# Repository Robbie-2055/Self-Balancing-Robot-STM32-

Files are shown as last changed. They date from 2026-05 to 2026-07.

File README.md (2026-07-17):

# STM32 Self-Balancing Robot





A two-wheeled self-balancing inverted pendulum robot built using an **STM32** microcontroller. The robot utilizes an **MPU6050** Inertial Measurement Unit (IMU) to sense its orientation, processes this data through a PID loop, and drives two **DC shaft motors** via an **L298N** motor driver to maintain perfect equilibrium.

This project is split into two distinct execution phases: prototyping with off-the-shelf modules and migrating to a custom-designed Printed Circuit Board (PCB).

---

## 📌 Project Roadmap

- [x] **Phase 1: Breadboard Prototype** 
  - Wire STM32, MPU6050, and L298N on a chassis.
  - Implement basic I2C communication and PWM motor control.
- [ ] **Phase 2: Firmware Optimization**
  - Tune the PID parameters ($K_p$, $K_i$, $K_d$).
- [ ] **Phase 3: Custom PCB Layout**
  - Design a compact, integrated schematic in KiCad

---

## 🛠️ Hardware Architecture

### Phase 1: Prototype Components
* **Microcontroller:** STM32 (e.g., STM32F103C8T6 "Blue Pill") — Handles high-speed sensor parsing, PID calculation, and PWM generation.
* **IMU Sensor:** MPU6050 — Configured via I2C to read accelerometer and gyroscope raw data.
* **Motor Driver:** L298N Dual H-Bridge — Regulates power and direction to the motors based on logic signals from the STM32.
* **Actuators:** 2x DC Gear Shaft Motors (equipped with quadrature encoders for speed feedback).
* **Power Supply:** 3S LiPo battery (11.1V) to power the motors, stepped down via buck converter to 5V/3.3V for logic.

### Phase 2: Custom Board Upgrades
To reduce wiring complexity, eliminate inductive noise, and minimize the physical footprint:
* **Integrated MCU:** STM32 chip placed directly on-board with dedicated decoupling capacitors and an external crystal oscillator.
* **On-board Sensors:** Hardwired MPU6050 footprint to prevent I2C signal degradation over jumper wires.
* **Motor Driver:** The L298N Motor driver together with all support components placed directly on the custom board

---

## Current developments

https://github.com/user-attachments/assets/f44257d5-607a-4bce-967d-3fb6638ffd92



https://github.com/user-attachments/assets/f6ba3c8e-9986-4cd3-9cd2-4a73ed5fd0c9

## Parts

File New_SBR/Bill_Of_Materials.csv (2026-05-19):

Id | Designator | Footprint | Quantity | Designation | Supplier and ref
1 | R2,R1 | R_0402_1005Metric | 2 | 4.7K
2 | R9 | R_0402_1005Metric | 1 | 1k
3 | R8,R6 | R_0402_1005Metric | 2 | 4.7k
4 | D1 | LED_0402_1005Metric | 1 | LED
5 | C21 | C_0402_1005Metric | 1 | 2.2nF
6 | C20,C19,C3 | C_0402_1005Metric | 3 | 0.1uF
7 | U3 | InvenSense_QFN-24_4x4mm_P0.5mm_NoMask | 1 | MPU-6050
8 | U1 | LQFP-64_10x10mm_P0.5mm | 1 | STM32F411RCTx
9 | D4,D5,D8,D10,D6,D7,D9,D11 | D_0603_1608Metric | 8 | 1N4007
10 | C15 | C_0603_1608Metric | 1 | 0.01uF
11 | C14,C16 | C_0603_1608Metric | 2 | 4.7uF
12 | C23,C25,C26,C1,C4,C2,C24 | C_0603_1608Metric | 7 | 100nF
13 | C12,C13 | C_0603_1608Metric | 2 | 1.5pF
14 | D12 | LED_0603_1608Metric | 1 | LED
15 | J1,J2 | TerminalBlock_Xinya_XY308-2.54-2P_1x02_P2.54mm_Horizontal | 2 | Screw_Terminal_01x02
16 | U4 | TO-220-15_P2.54x5.08mm_StaggerOdd_Lead4.58mm_Vertical | 1 | L298N
17 | R3,R4,R7 | R_0603_1608Metric | 3 | 10K
18 | J3 | TerminalBlock_Xinya_XY308-2.54-3P_1x03_P2.54mm_Horizontal | 1 | Screw_Terminal_01x03
19 | R5 | R_0603_1608Metric | 1 | 1K
20 | C27 | C_0603_1608Metric | 1 | 10uF
21 | J4 | PinSocket_1x06_P2.54mm_Vertical | 1 | Conn_01x06_Socket
22 | C9 | C_0603_1608Metric | 1 | 2.2uF
23 | C10,C11 | C_0603_1608Metric | 2 | 20pF
24 | C17,C18 | C_0603_1608Metric | 2 | 220uF
25 | PWR_SW3 | SW_Slide_SPDT_Straight_CK_OS102011MS2Q | 1 | SW_SPDT
26 | RESET1 | SW_SPST_TL3305A | 1 | SW_Push
27 | J6 | PinSocket_1x04_P2.54mm_Vertical | 1 | Conn_01x04_Socket
28 | 9v_PWR1 | PinHeader_1x02_P2.54mm_Vertical | 1 | Jumper_3
29 | 5v_Reg1 | TO-220-3_Vertical | 1 | LM7805_TO220
30 | 3.3V_Reg1 | TO-220-3_Vertical | 1 | LM1117T-3.3
31 | Y1 | Crystal_HC49-U_Vertical | 1 | 25MHZ 9PF
32 | Y2 | Crystal_C38-LF_D3.0mm_L8.0mm_Vertical | 1 | 32.768K 6PF

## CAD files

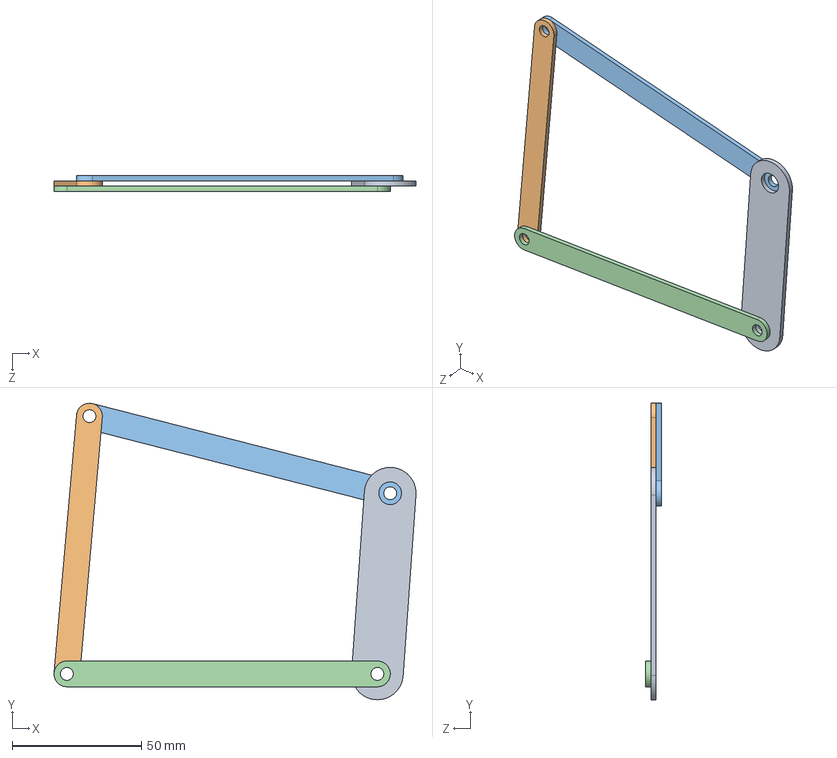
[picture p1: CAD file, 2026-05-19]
Project Selfbalancing robot/4bar_linkage.SLDASM
139.9 x 114.6 x 6.00 mm
link1
link2
link3
link4

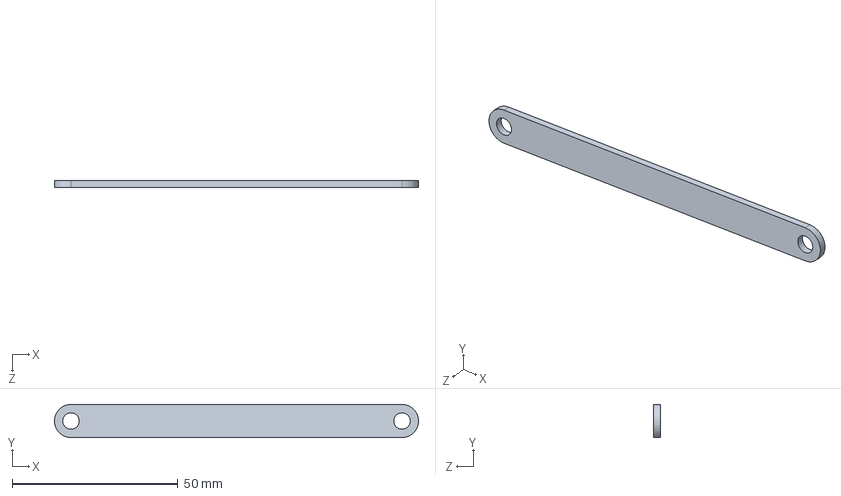
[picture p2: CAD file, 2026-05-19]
Project Selfbalancing robot/Links/link3.SLDPRT
110.0 x 10.0 x 2.00 mm

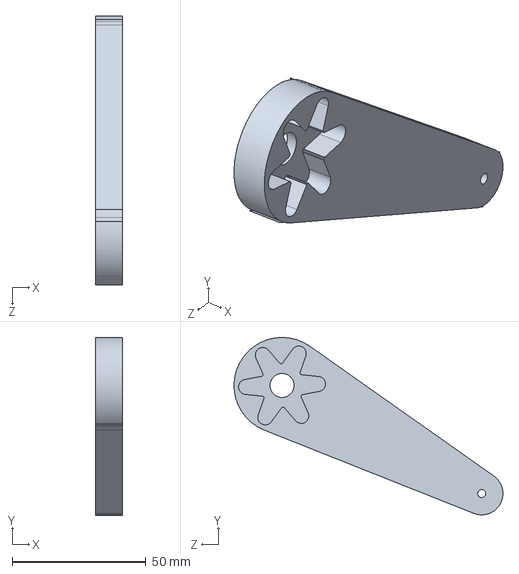
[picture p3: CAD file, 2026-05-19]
Project Selfbalancing robot/thigh-2_faces.SLDPRT
10.0 x 66.7 x 100.7 mm

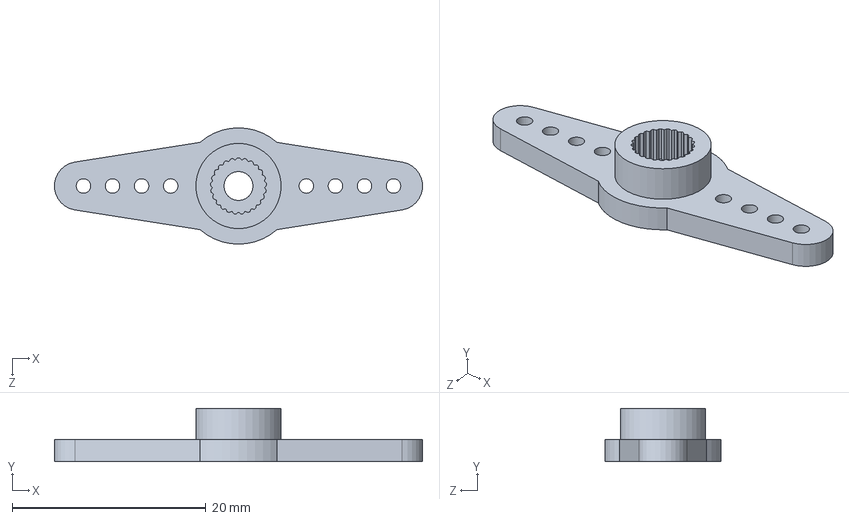
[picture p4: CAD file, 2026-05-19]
Project Selfbalancing robot/2horn_mount.SLDPRT
38.0 x 5.50 x 12.0 mm

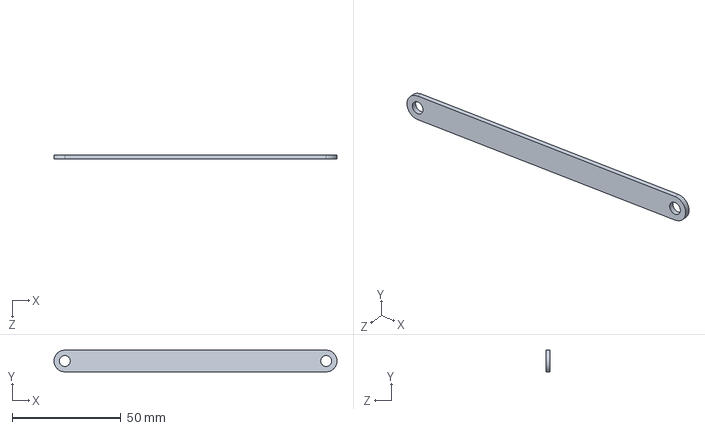
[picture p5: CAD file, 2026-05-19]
Project Selfbalancing robot/Links/link2.SLDPRT
130.0 x 10.0 x 2.00 mm

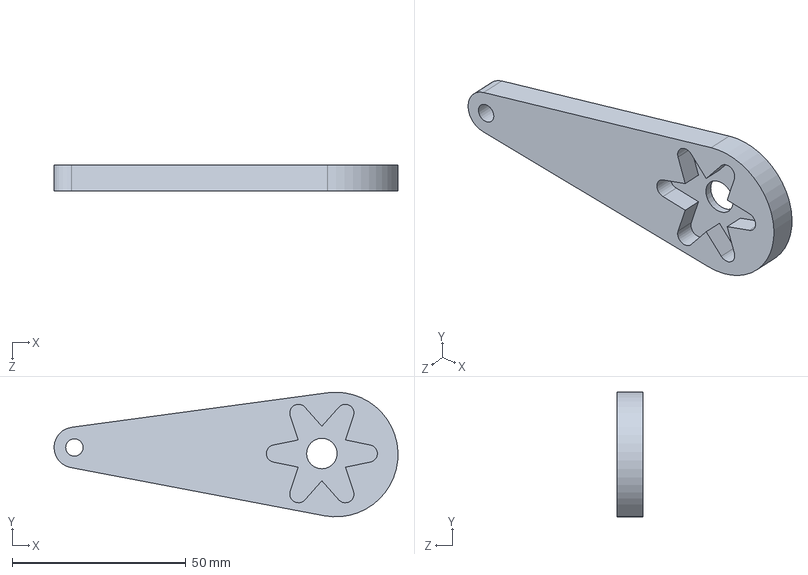
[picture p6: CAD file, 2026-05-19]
Project Selfbalancing robot/My_parts/Thigh.SLDPRT
99.1 x 35.9 x 7.50 mm

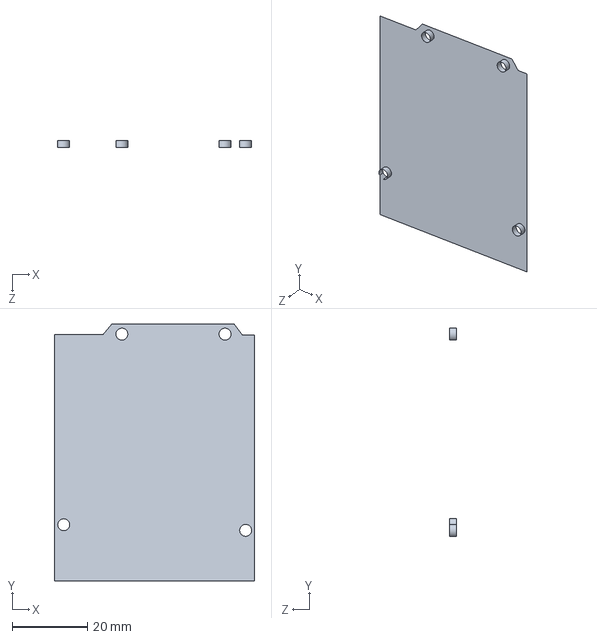
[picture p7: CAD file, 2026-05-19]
Project Selfbalancing robot/Arduino_model.SLDPRT
53.4 x 68.5 x 1.75 mm

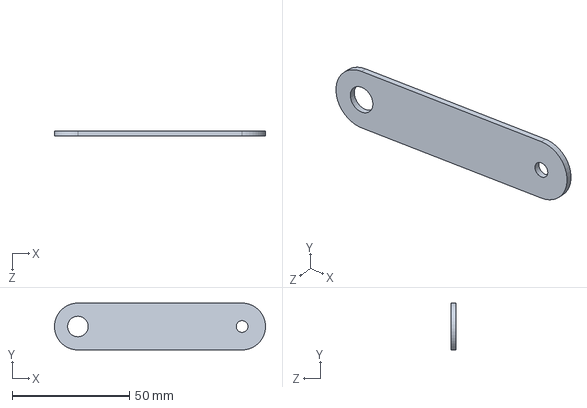
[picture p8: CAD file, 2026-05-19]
Project Selfbalancing robot/Links/link4.SLDPRT
89.9 x 20.0 x 2.00 mm

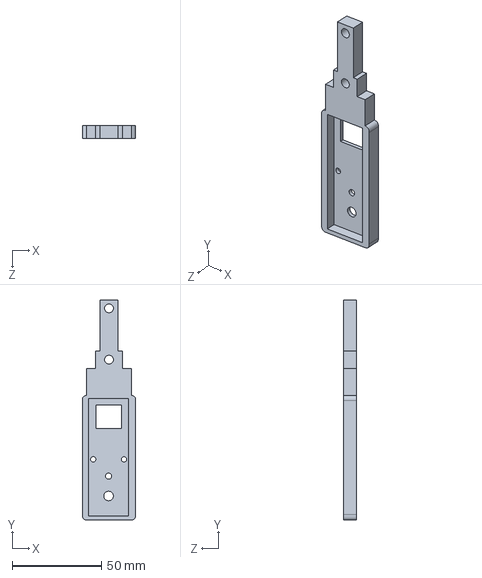
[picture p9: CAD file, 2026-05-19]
Project Selfbalancing robot/My_parts/calf1.SLDPRT
30.0 x 123.5 x 7.50 mm

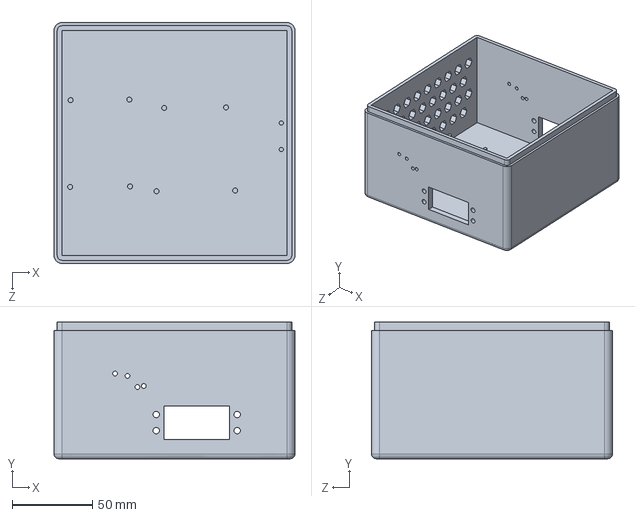
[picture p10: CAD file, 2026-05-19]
Project Selfbalancing robot/box.SLDPRT
150.0 x 85.0 x 150.0 mm

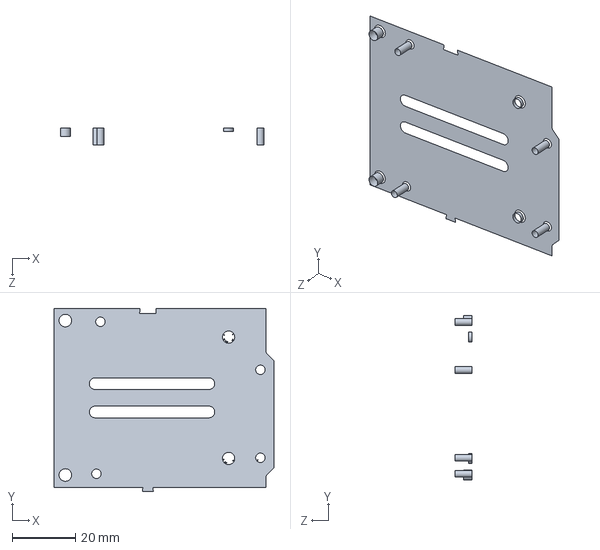
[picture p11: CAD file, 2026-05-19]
Project Selfbalancing robot/Arduino base.SLDPRT
69.8 x 58.2 x 5.80 mm

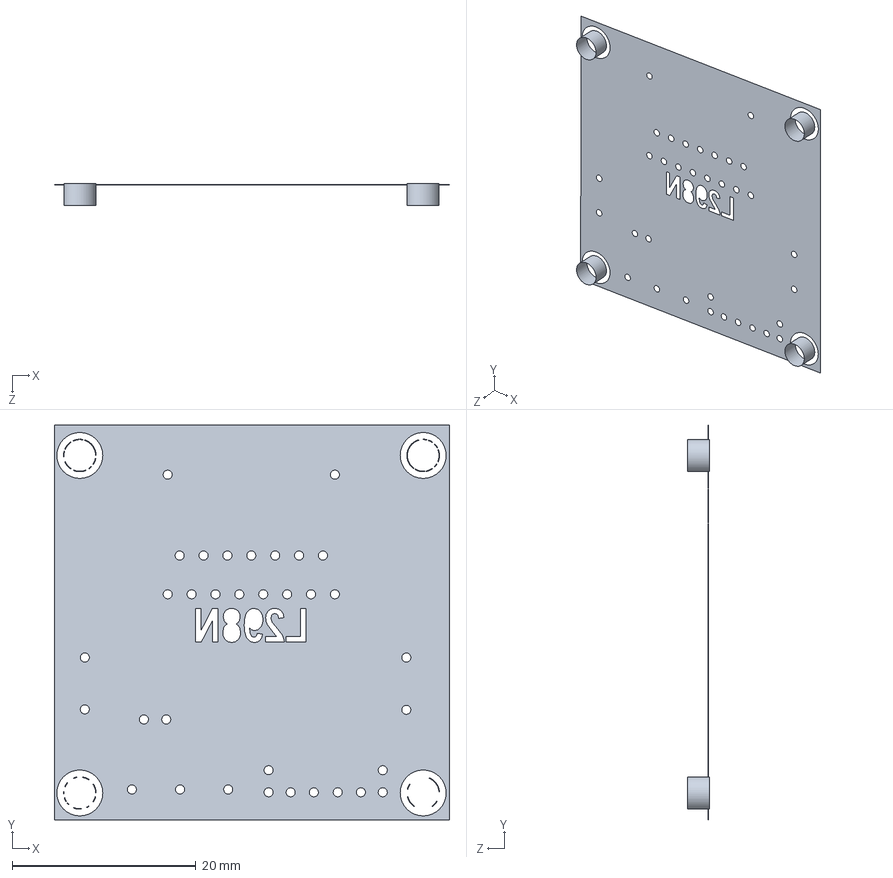
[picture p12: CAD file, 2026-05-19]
Project Selfbalancing robot/L298N_Driver_DC_Motor_Stepper_Motor_model.SLDPRT
43.0 x 43.0 x 2.40 mm

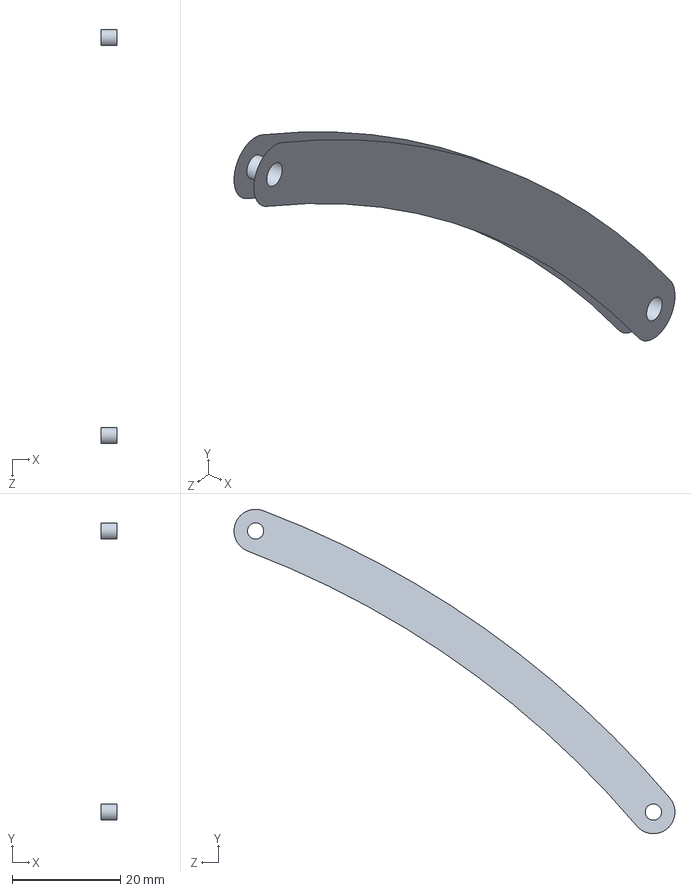
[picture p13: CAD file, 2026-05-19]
Project Selfbalancing robot/SH-2_faces.SLDPRT
3.00 x 59.9 x 81.5 mm

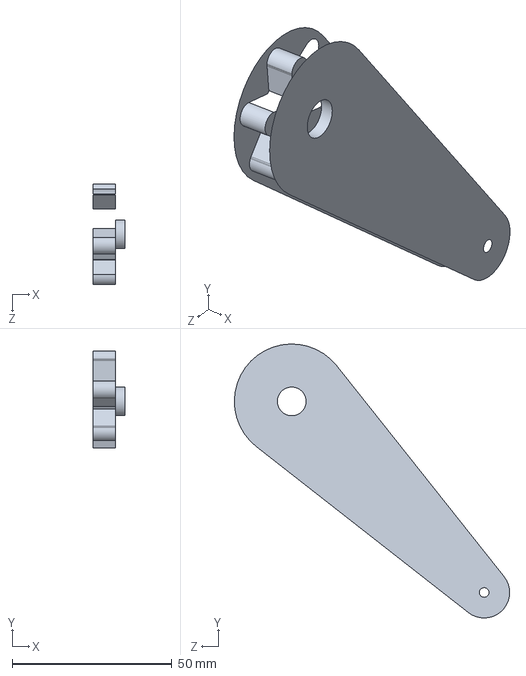
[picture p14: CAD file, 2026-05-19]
Project Selfbalancing robot/thigh-1_faces.SLDPRT
10.0 x 85.9 x 86.3 mm

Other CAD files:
Project Selfbalancing robot/SelfBalancing_CAD_Assembly.SLDASM
Project Selfbalancing robot/My_parts/shock_absorber.SLDPRT
Project Selfbalancing robot/Links/link1.SLDPRT
Project Selfbalancing robot/Wheel D65x25.SLDPRT
Project Selfbalancing robot/4Horn_mount.SLDPRT
Project Selfbalancing robot/6HORN_mount.SLDPRT
Project Selfbalancing robot/9v_battery_model.SLDPRT
Project Selfbalancing robot/9vcase.SLDPRT
Project Selfbalancing robot/L298N_mount_v2.SLDPRT
Project Selfbalancing robot/MG996R Servo Motor.sldprt
Project Selfbalancing robot/MPU-6050_model.SLDPRT
Project Selfbalancing robot/Power_distribution_unit.SLDPRT
Project Selfbalancing robot/Power_distrubution_unit.SLDPRT
Project Selfbalancing robot/SH-1_faces.SLDPRT
Project Selfbalancing robot/TrayForMPU6050.SLDPRT
Project Selfbalancing robot/calf-1_faces.SLDPRT
Project Selfbalancing robot/calf-2_faces.SLDPRT
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

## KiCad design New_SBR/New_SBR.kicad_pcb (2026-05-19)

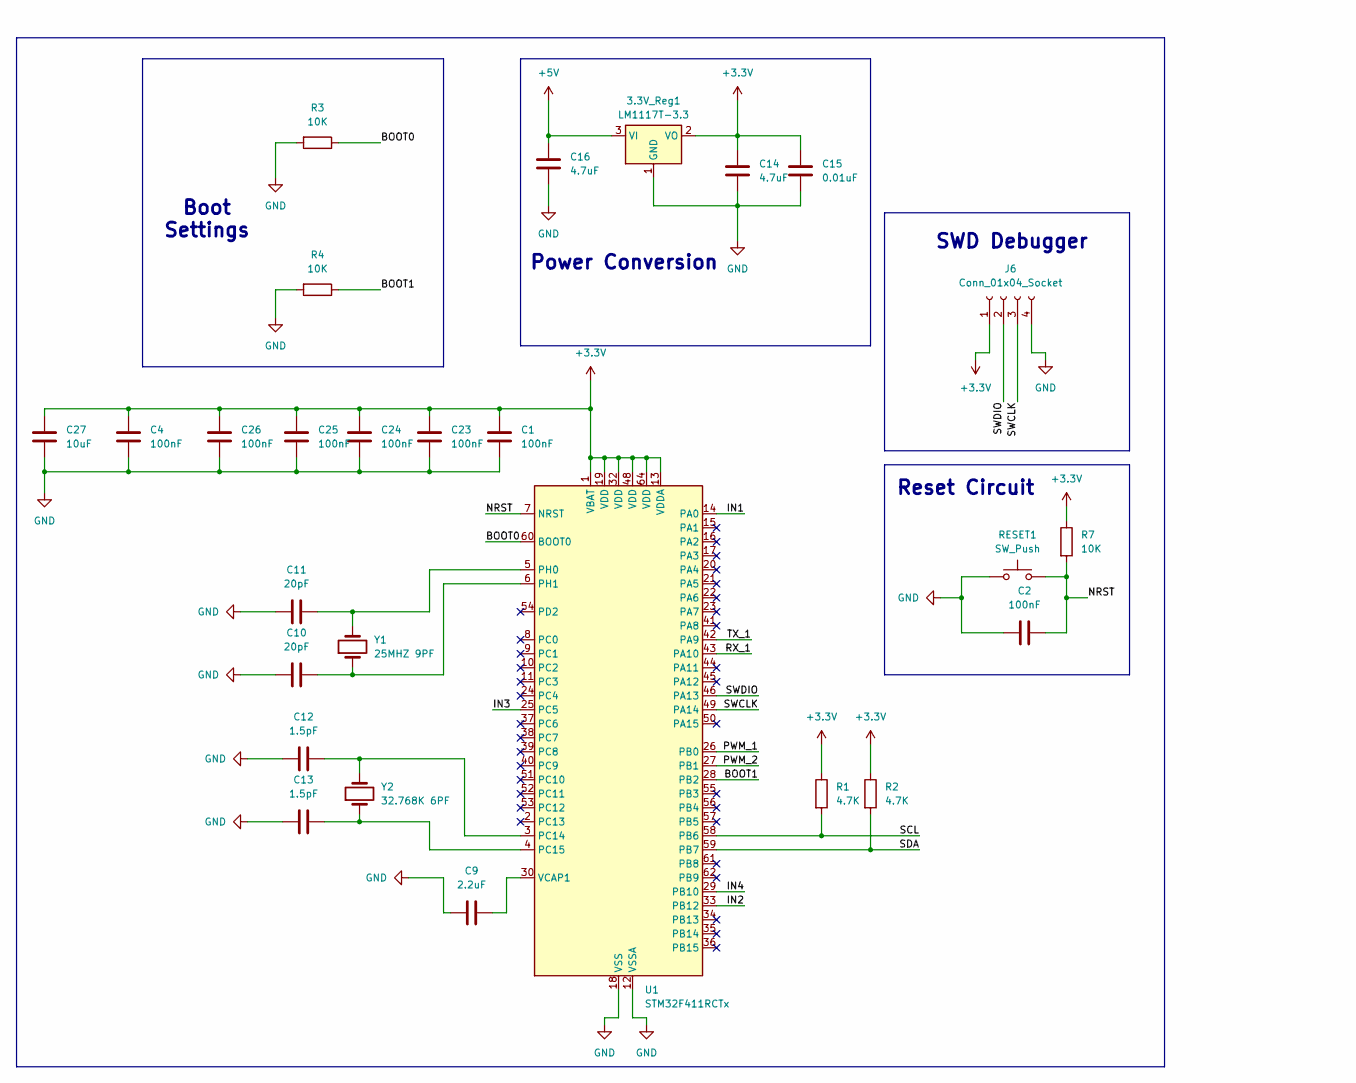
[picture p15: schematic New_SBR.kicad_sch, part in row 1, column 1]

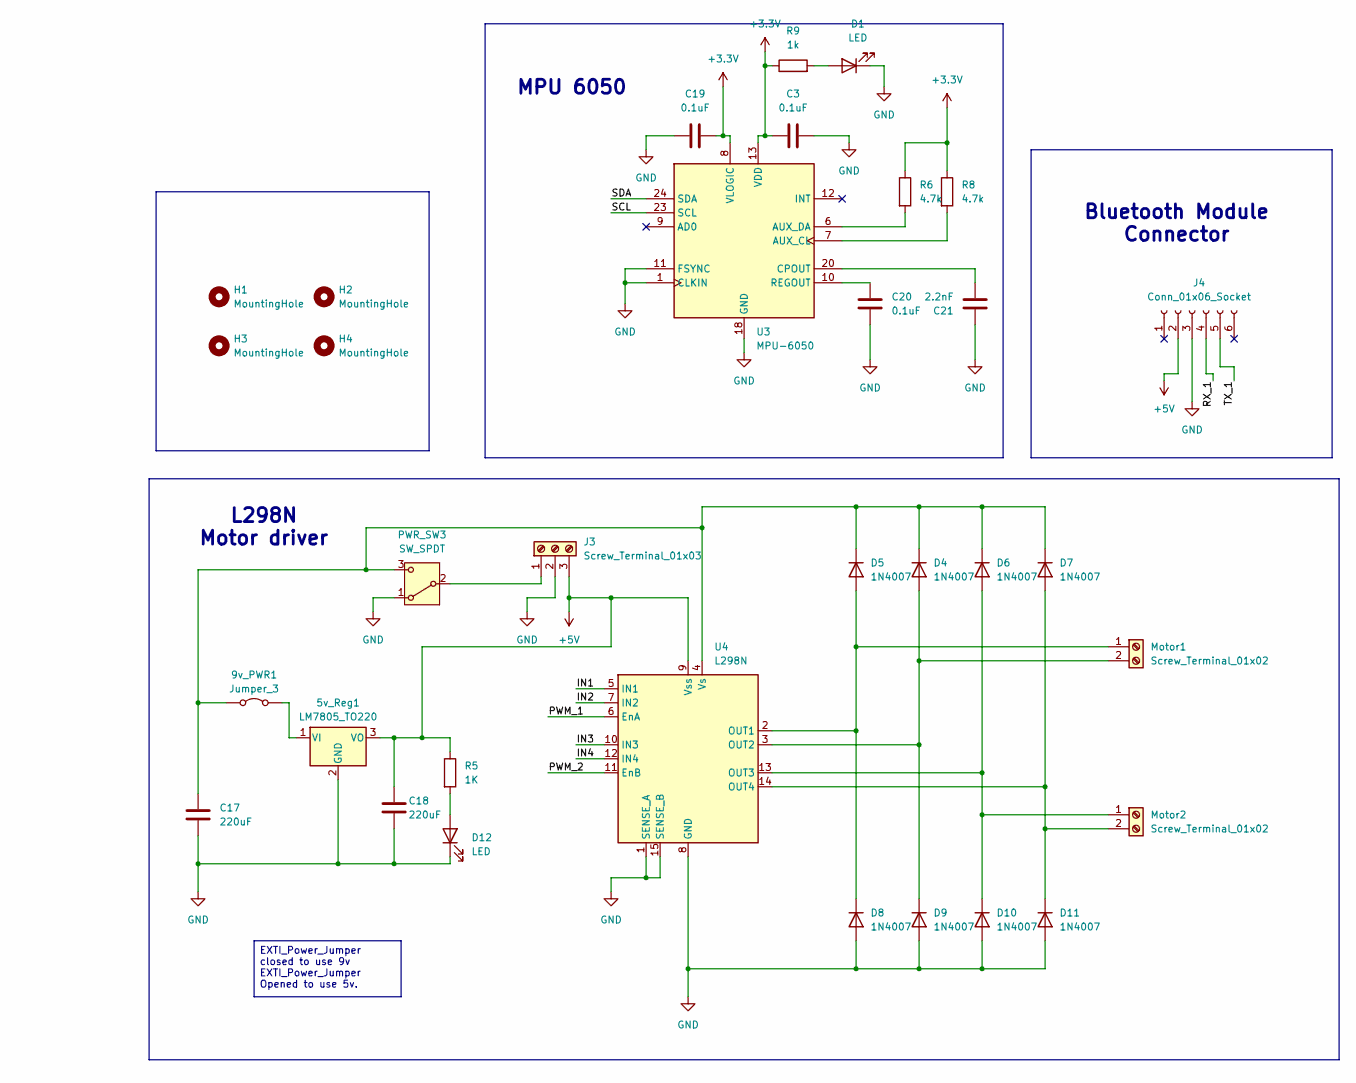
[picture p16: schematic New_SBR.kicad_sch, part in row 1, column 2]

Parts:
3.3V_Reg1: LM1117T-3.3; TO-220-3_Vertical
5v_Reg1: LM7805_TO220; TO-220-3_Vertical
9v_PWR1: Jumper_3; PinHeader_1x02_P2.54mm_Vertical
C1, C2, C4, C23, C24, C25, C26: 100nF; C_0603_1608Metric
C3, C19, C20: 0.1uF; C_0402_1005Metric
C9: 2.2uF; C_0603_1608Metric
C10, C11: 20pF; C_0603_1608Metric
C12, C13: 1.5pF; C_0603_1608Metric
C14, C16: 4.7uF; C_0603_1608Metric
C15: 0.01uF; C_0603_1608Metric
C17, C18: 220uF; C_0603_1608Metric
C21: 2.2nF; C_0402_1005Metric
C27: 10uF; C_0603_1608Metric
D1: LED; LED_0402_1005Metric
D4, D5, D6, D7, D8, D9, D10, D11: 1N4007; D_SMA
D12: LED; LED_0603_1608Metric
H1, H2, H3, H4: MountingHole; MountingHole_2.2mm_M2
J3: Screw_Terminal_01x03; TerminalBlock_Phoenix_MKDS-1,5-3-5.08_1x03_P5.08mm_Horizont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
J4: Conn_01x06_Socket; PinSocket_1x06_P2.54mm_Vertical
J6: Conn_01x04_Socket; PinSocket_1x04_P2.54mm_Vertical
Motor1, Motor2: Screw_Terminal_01x02; TerminalBlock_Phoenix_MKDS-1,5-2-5.08_1x02_P5.08mm_Horizont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
PWR_SW3: SW_SPDT; SW_Slide_SPDT_Straight_CK_OS102011MS2Q
R1, R2: 4.7K; R_0402_1005Metric
R3, R4, R7: 10K; R_0603_1608Metric
R5: 1K; R_0603_1608Metric
R6, R8: 4.7k; R_0402_1005Metric
R9: 1k; R_0402_1005Metric
RESET1: SW_Push; SW_SPST_TL3305A
U1: STM32F411RCTx; LQFP-64_10x10mm_P0.5mm
U3: MPU-6050; InvenSense_QFN-24_4x4mm_P0.5mm_NoMask
U4: L298N; TO-220-15_P2.54x5.08mm_StaggerOdd_Lead4.58mm_Vertical
Y1: 25MHZ 9PF; Crystal_HC49-U_Vertical
Y2: 32.768K 6PF; Crystal_C38-LF_D3.0mm_L8.0mm_Vertical

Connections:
+3.3V: 3.3V_Reg1.2 (VO), C1.2, C3.1, C4.2, C14.2, C15.2, C19.2, C23.2, C24.2, C25.2, C26.2, C27.2, J6.1, R1.1, R2.1, R6.1, R7.1, R8.1, R9.1, U1.1 (VBAT), U1.13 (VDDA), U1.19 (VDD), U1.32 (VDD), U1.48 (VDD), U1.64 (VDD), U3.8 (VLOGIC), U3.13 (VDD)
+5V: 3.3V_Reg1.3 (VI), 5v_Reg1.3 (VO), C16.2, C18.2, J3.3, J4.2, R5.1, U4.9 (Vss)
/BOOT0: R3.1, U1.60 (BOOT0)
/BOOT1: R4.1, U1.28 (PB2)
/IN1: U1.14 (PA0), U4.5 (IN1)
/IN2: U1.33 (PB12), U4.7 (IN2)
/IN3: U1.25 (PC5), U4.10 (IN3)
/IN4: U1.29 (PB10), U4.12 (IN4)
/NRST: C2.1, R7.2, RESET1.2, U1.7 (NRST)
/PWM_1: U1.26 (PB0), U4.6 (EnA)
/PWM_2: U1.27 (PB1), U4.11 (EnB)
/RX_1: J4.4, U1.43 (PA10)
/SCL: R1.2, U1.58 (PB6), U3.23 (SCL)
/SDA: R2.2, U1.59 (PB7), U3.24 (SDA)
/SWCLK: J6.3, U1.49 (PA14)
/SWDIO: J6.2, U1.46 (PA13)
/TX_1: J4.5, U1.42 (PA9)
GND: 3.3V_Reg1.1 (GND), 5v_Reg1.2 (GND), C1.1, C2.2, C3.2, C4.1, C9.1, C10.1, C11.1, C12.1, C13.1, C14.1, C15.1, C16.1, C17.1, C18.1, C19.1, C20.1, C21.2, C23.1, C24.1, C25.1, C26.1, C27.1, D1.1 (K), D8.2 (A), D9.2 (A), D10.2 (A), D11.2 (A), D12.1 (K), J3.2, J4.3, J6.4, PWR_SW3.1 (A), R3.2, R4.2, RESET1.1, U1.12 (VSSA), U1.18 (VSS), U1.31 (VSS), U1.47 (VSS), U1.63 (VSS), U3.1 (CLKIN), U3.11 (FSYNC), U3.18 (GND), U4.1 (SENSE_A), U4.8 (GND), U4.15 (SENSE_B)
unnamed: 5v_Reg1.1 (VI), 9v_PWR1.2 (B)
unnamed: 9v_PWR1.1 (A), C17.2, D4.1 (K), D5.1 (K), D6.1 (K), D7.1 (K), PWR_SW3.3 (C), U4.4 (Vs)
unnamed: D1.2 (A), R9.2
unnamed: D4.2 (A), D9.1 (K), Motor1.2, U4.3 (OUT2)
unnamed: D5.2 (A), D8.1 (K), Motor1.1, U4.2 (OUT1)
unnamed: D6.2 (A), D10.1 (K), Motor2.1, U4.13 (OUT3)
unnamed: D7.2 (A), D11.1 (K), Motor2.2, U4.14 (OUT4)
unnamed: D12.2 (A), R5.2
unnamed: J3.1, PWR_SW3.2 (B)
unnamed: C12.2, U1.3 (PC14), Y2.2
unnamed: C13.2, U1.4 (PC15), Y2.1
unnamed: C11.2, U1.5 (PH0), Y1.2
unnamed: C10.2, U1.6 (PH1), Y1.1
unnamed: C9.2, U1.30 (VCAP1)
unnamed: R8.2, U3.7 (AUX_CL)
unnamed: R6.2, U3.6 (AUX_DA)
unnamed: C21.1, U3.20 (CPOUT)
unnamed: C20.2, U3.10 (REGOUT)

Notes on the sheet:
Boot Settings
L298N Motor driver
Power Conversion
SWD Debugger
Reset Circuit
Bluetooth Module Connector
MPU 6050
EXTI_Power_Jumper closed to use 9v EXTI_Power_Jumper Opened to use 5v.

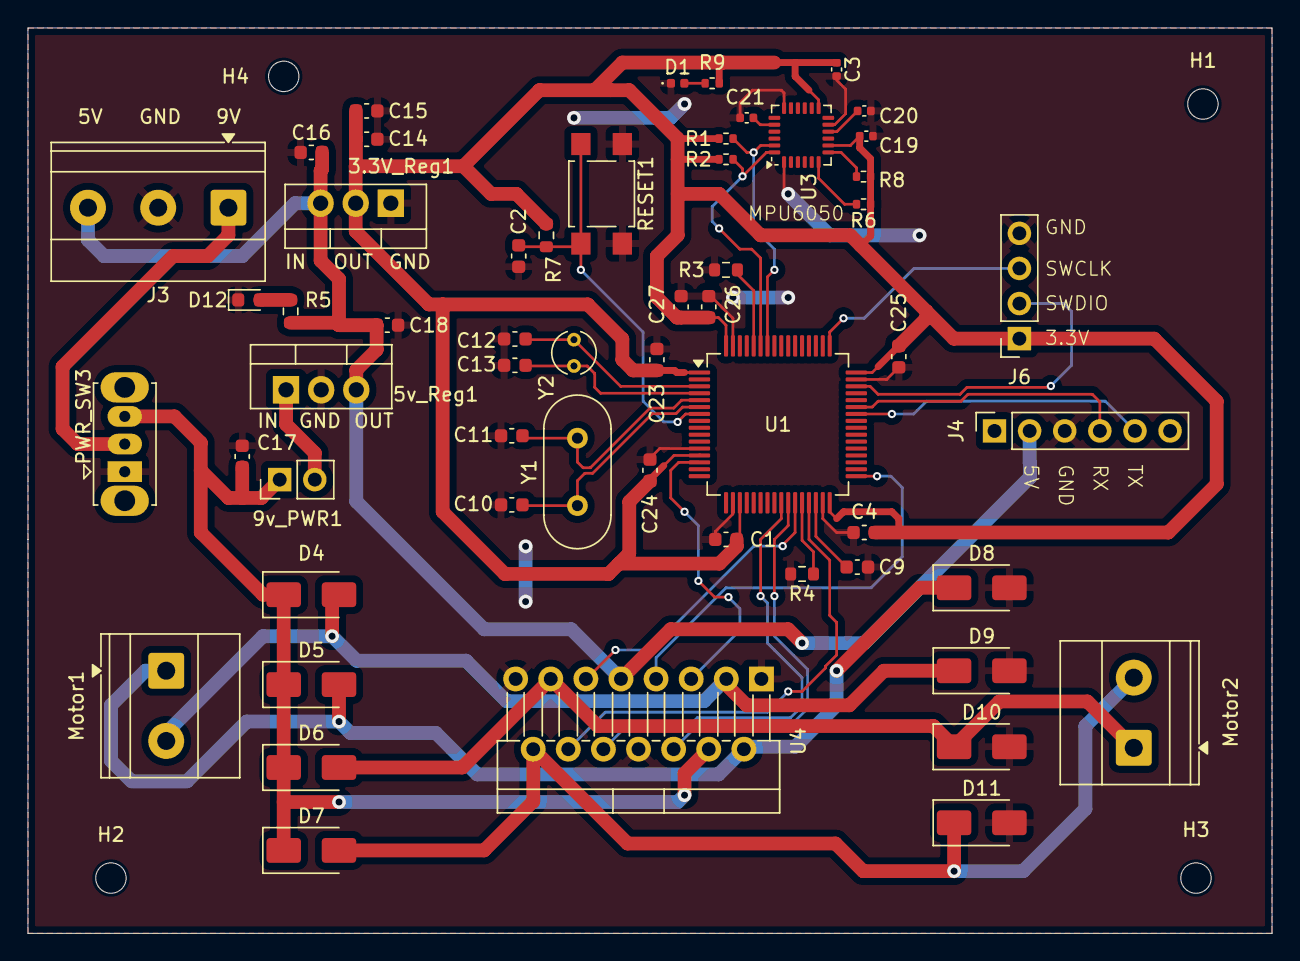
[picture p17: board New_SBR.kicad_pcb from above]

Board: 2 copper layers, 90.0 x 65.5 mm, 60 parts (0 on the bottom side), 36 nets.

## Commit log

2026-05-19 Clarify motor description and sensor fusion method
    Updated description to specify 'two DC shaft motors' and replaced 'Complementary Filter' with 'Kalman Filter' in the sensor fusion section.
2026-05-19 Revise sensor fusion and PID control explanations
    Updated sensor fusion and PID control descriptions for clarity.
2026-05-19 Fix formatting of PID control parameters in README
    Updated PID control parameters formatting in README.
2026-05-19 Improve formatting of sensor fusion and control sections
    Reformatted text for better readability in the README.
2026-05-19 Update README with current developments and images
    Removed outdated image links and added current developments section with new images.
